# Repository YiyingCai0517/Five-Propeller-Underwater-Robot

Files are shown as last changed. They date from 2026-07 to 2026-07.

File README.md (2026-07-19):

# Five-Propeller Underwater Robot | 五推进器水下机器人

[中文](#中文说明) · [English](#english-version) · [中文独立版 / Chinese-only version](README.zh-CN.md)






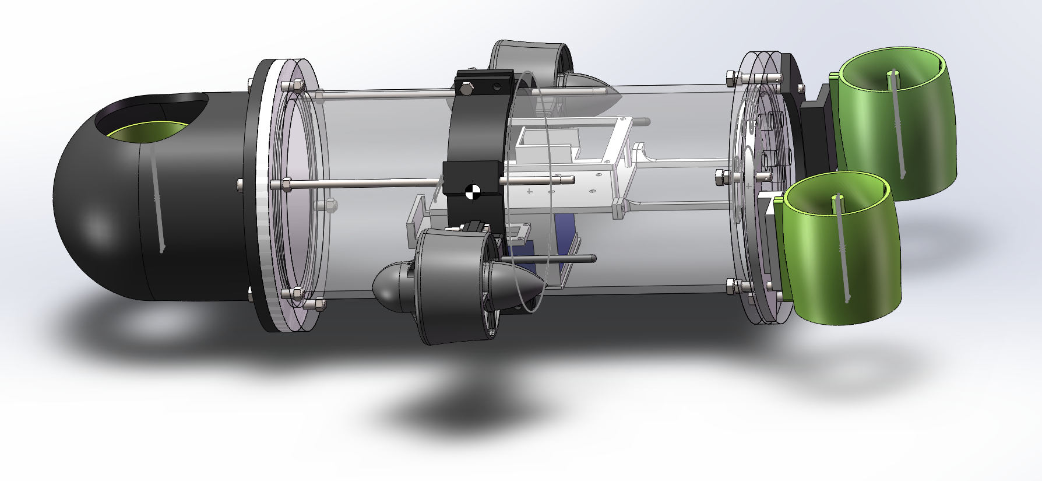
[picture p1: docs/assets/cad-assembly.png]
SolidWorks 最终装配体 / Final SolidWorks assembly


## 中文说明

本项目是一款基于 STM32F407 和 FreeRTOS 的小型五推进器水下机器人课程设计。机器人采用三个垂直推进器控制升沉、俯仰和横滚，两个水平推进器控制前进、后退和偏航。仓库已将嵌入式固件、SolidWorks 机械设计、LoRa 上位机、Python 六自由度仿真、ROS1 模型、样机照片和工程说明整理为可直接浏览和审查的源文件。

### 项目功能

- 五推进器驱动：三个垂直推进器控制升沉、俯仰和横滚，两个水平推进器控制纵向运动和偏航。
- 支持 `IDLE`、定深 `HOVER`、航向保持 `AUTO`、绝对航向转向 `TURN` 和定时方形轨迹 `SQUARE` 模式。
- 使用四个 PID 控制环、解析式推进器混控和按比例限幅。
- FreeRTOS 分离控制、压力采样、通信和心跳任务。
- 使用 H30 串口 IMU、MS5837-30BA 压力传感器、E22-400T30D LoRa 和五路 ESC PWM，并以 2 Hz 返回遥测数据。
- 提供基于 Python/pyserial 的指令终端、状态显示和 CSV 日志记录。
- 提供独立 Python 六自由度任务仿真和 ROS1 URDF/STL 可视化模型。

### 样机与水池试验

| 最终装配样机 | 方形轨迹试验画面 |
| --- | --- |
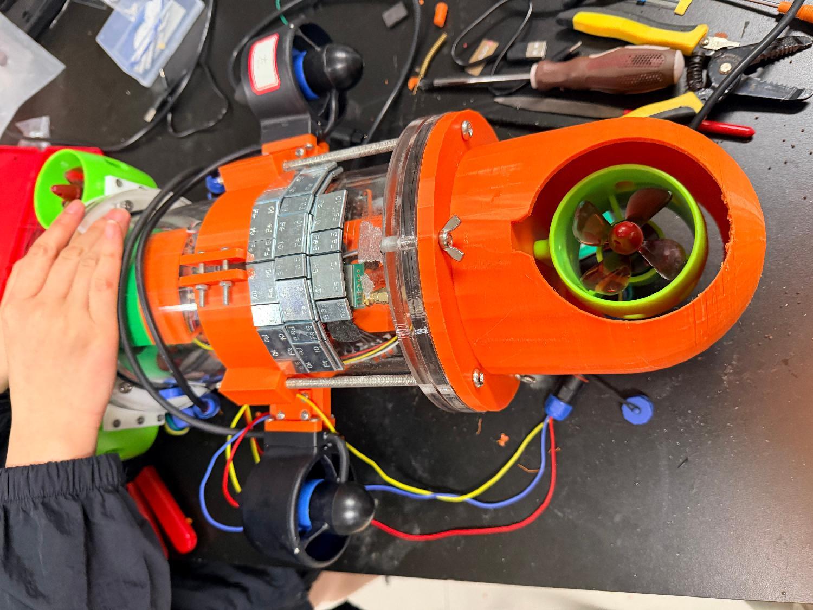
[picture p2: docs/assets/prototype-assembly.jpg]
最终装配阶段的样机
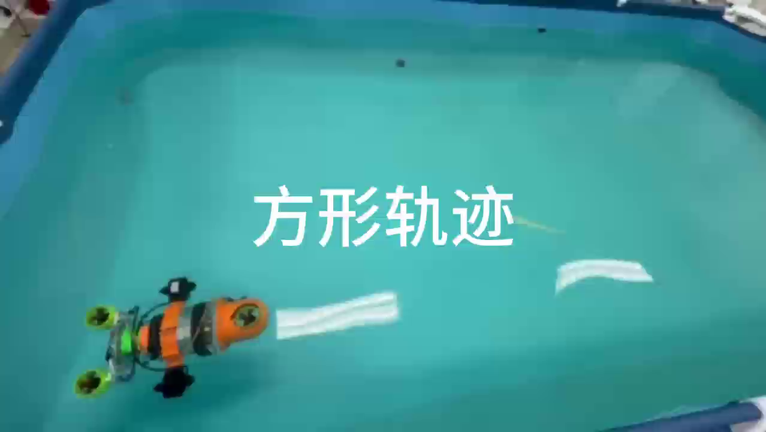
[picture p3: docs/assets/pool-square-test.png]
水池方形轨迹试验画面
|  |  |

### 系统组成

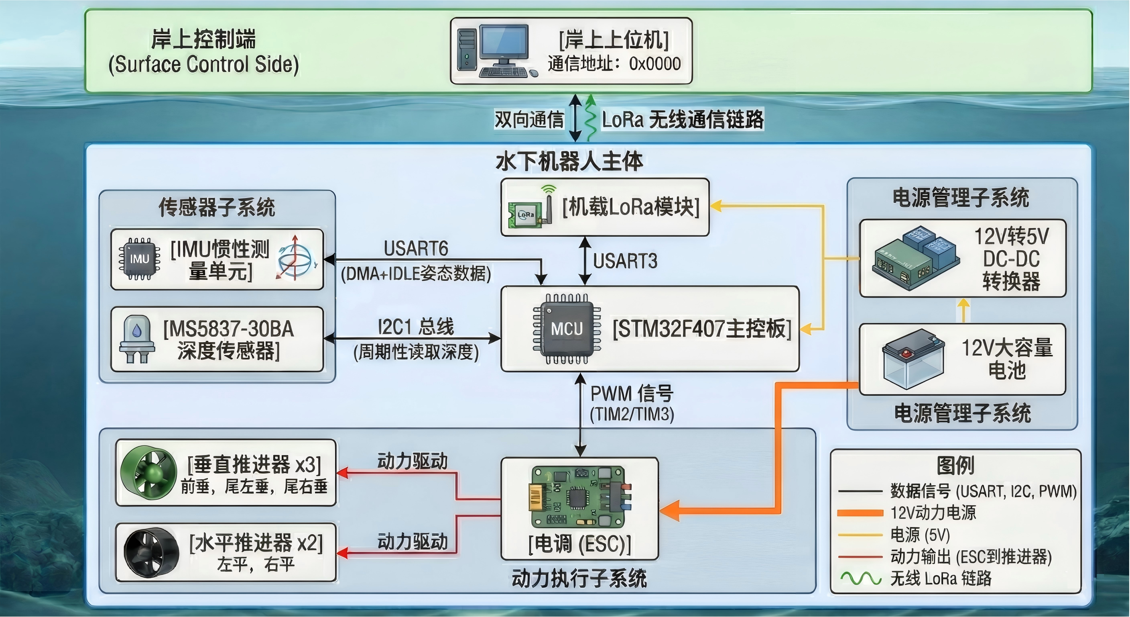
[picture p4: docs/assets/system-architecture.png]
电气与通信架构


| 层级 | 主要组件 | 职责 |
| --- | --- | --- |
| 传感器 | H30 IMU、MS5837-30BA | 姿态、加速度、压力和深度测量 |
| 控制器 | STM32F407 + FreeRTOS | 状态机、PID、推进器混控和通信 |
| 执行机构 | 5 个 ESC 驱动推进器 | 升沉、俯仰、横滚、纵向运动和偏航 |
| 通信 | E22 LoRa（UART/DMA） | 指令接收和遥测发送 |
| 上位机 | Python + pyserial | 指令输入、状态显示和 CSV 日志 |
| 数值仿真 | Python + NumPy/Matplotlib | 六自由度模型和可复现实例 |
| 机器人可视化 | ROS1 URDF/STL | 几何模型和关节显示 |

### 硬件概况

主要硬件包括 STM32F407、H30 IMU、MS5837-B30 压力传感器、E22-400T30D 无线模块、三星 21700-50S 电芯定制电池组、两个已安装的 Viocean T60 水平推进器、三个垂直推进器，以及直径 130 mm、长度 250 mm 的透明耐压舱。项目总预算为人民币 2,441.3 元。数量差异、备用推进器和缺失的电气资料请参见[硬件与预算说明](docs/hardware.md)。

### 仓库结构

```text
Five-Propeller-Underwater-Robot/
├── firmware/                 STM32F407 CubeMX/CMake 固件
├── tools/pc/                 Python LoRa 上位机与遥测记录工具
├── mechanical/solidworks/    SolidWorks 零件与装配体源文件
├── simulation/python/        独立六自由度数值仿真
├── simulation/ros/           ROS1 URDF/STL 可视化包
├── docs/                     架构、算法、协议、硬件和代码审查文档
├── .github/                  Issue 与 Pull Request 模板
├── README.md                 中英双语主页
├── README.zh-CN.md           独立中文说明
└── LICENSE
```

### 快速开始

#### 1. 查看或编译固件

需要 CMake 3.22+、Ninja 和 Arm GNU Toolchain（`arm-none-eabi-gcc`）。

```bash
cd firmware
cmake --preset Debug
cmake --build --preset Debug
```

可使用 STM32CubeMX 查看或重新生成 `firmware/unify_v1_0307.ioc`。烧录前必须结合实物核对引脚、接线、PWM 中值与范围、传感器设置、电机方向和安全限值。详见[固件说明](firmware/README.md)。

#### 2. 运行 LoRa 上位机

```bash
python -m venv .venv
# Windows PowerShell: .venv\Scripts\Activate.ps1
python -m pip install -r tools/pc/requirements.txt
python tools/pc/lora_pc.py COM6 9600
```

请将 `COM6` 和 `9600` 替换为实际串口和波特率。详见[上位机说明](tools/pc/README.md)和[通信协议](docs/protocol.md)。

#### 3. 运行数值仿真

```bash
cd simulation/python
python -m pip install -r requirements.txt
python scripts/smoke_test.py
python run_all_tasks.py
```

仿真参数目前属于工程假设，仿真误差（尤其是很小的深度 RMSE）不能作为实物精度。详见[仿真说明](simulation/python/README.md)。

#### 4. 查看 ROS 模型

将 `simulation/ros/simulatedrobot` 放入 ROS1 catkin 工作空间，然后运行：

```bash
roslaunch simulatedrobot display_fixed.launch
```

该包用于几何可视化，不是经过验证的水下 Gazebo 动力学模型。详见[ROS/URDF 说明](simulation/ros/README.md)。

### 固件控制模式

| 模式 | 行为 |
| --- | --- |
| `IDLE` | 输出中性 PWM，并清空所有 PID 状态 |
| `HOVER` | 保持目标深度和水平姿态，纵向推力为零 |
| `AUTO` | 保持目标深度和进入模式时的航向，同时施加设定纵向推力 |
| `TURN` | 停止纵向推进并转到指定偏航角；误差进入 ±3° 后切换为悬停 |
| `SQUARE` | 交替执行定时直线航段和 90° 转向，共完成四条边 |

任务时序、PID 参数、控制方程、混控映射、仿真差异和调参顺序见[控制算法说明](docs/control-algorithm.md)。

### 项目文档

- [系统架构与数据流](docs/architecture.md)
- [控制算法](docs/control-algorithm.md)
- [LoRa 通信协议](docs/protocol.md)
- [硬件与预算](docs/hardware.md)
- [静态代码审查结果](docs/code-review.md)
- [安全说明与已知限制](docs/safety.md)
- [机械设计文件](mechanical/README.md)

### 参与贡献与许可证

请阅读[贡献指南](CONTRIBUTING.md)。源代码、配置和文档应以普通 Git 文件提交，请勿重新提交编译目录、IDE 缓存、仿真输出、遥测日志或替代用 ZIP 压缩包。本仓库采用 [MIT License](LICENSE)；STM32 HAL、CMSIS、FreeRTOS 和其他第三方组件仍遵循各自源码目录中的许可声明。

---

## English version

This repository contains an STM32F407/FreeRTOS course project for a compact underwater robot with three vertical and two horizontal thrusters. It brings the firmware, SolidWorks design, PC LoRa tool, Python 6-DOF simulation, ROS1 model, prototype images, and engineering notes together as directly reviewable source files.

> [!CAUTION]
> This is a teaching and research prototype, not a certified underwater vehicle. The current depth conversion appears to be approximately 10× too small, and active modes do not yet have a LoRa command-loss watchdog. Read [Safety and known limitations](docs/safety.md), and verify wiring, motor direction, and protection measures before powering the thrusters or attempting closed-loop pool tests.

### Highlights

- Five-thruster actuation: three vertical units for heave, pitch, and roll, plus two horizontal units for surge and yaw.
- `IDLE`, depth `HOVER`, heading-hold `AUTO`, absolute-yaw `TURN`, and timed `SQUARE` modes.
- Four firmware PID loops with an analytic mixer and proportional saturation handling.
- FreeRTOS separation of control, pressure sampling, communication, and heartbeat work.
- H30 serial IMU, MS5837-30BA pressure sensor, E22-400T30D LoRa, five ESC PWM channels, and 2 Hz telemetry.
- Python/pyserial command console with live status and CSV logging.
- Standalone Python 6-DOF task simulation and ROS1 URDF/STL visualization.

### Prototype and pool test

The images in the [Chinese section](#样机与水池试验) show the final assembly and a square-path pool test. The course report records demonstrations of depth control, straight motion, turning, and a timed square sequence. These tests establish prototype feasibility; they do not establish a pressure rating, navigation accuracy, or safety certification.

### System overview

| Layer | Main components | Responsibility |
| --- | --- | --- |
| Sensors | H30 IMU, MS5837-30BA | Attitude, acceleration, pressure, and depth |
| Controller | STM32F407 + FreeRTOS | State machine, PID, mixing, and communication |
| Actuation | 5 ESC-driven thrusters | Heave, pitch, roll, surge, and yaw |
| Communication | E22 LoRa over UART/DMA | Commands and telemetry |
| Ground station | Python + pyserial | Command entry, display, and CSV logging |
| Numerical simulation | Python + NumPy/Matplotlib | 6-DOF model and repeatable task examples |
| Robot visualization | ROS1 URDF/STL | Geometry and joint display |

### Hardware snapshot

The report lists an STM32F407, H30 IMU, MS5837-B30 sensor, E22-400T30D radio, a custom Samsung 21700-50S battery pack, two installed Viocean T60 horizontal thrusters, three vertical thrusters, and a 130 mm × 250 mm transparent housing. Its historical project total is CNY 2,441.3. See [Hardware and budget](docs/hardware.md) for quantities, the spare-thruster discrepancy, and missing electrical documentation.

### Repository layout

The bilingual directory tree is shown in the [Chinese section](#仓库结构). The two original ZIP archives were replaced by source trees so GitHub can browse, search, diff, and review the project directly.

### Quick start

#### 1. Inspect or build the firmware

Requirements: CMake 3.22+, Ninja, and Arm GNU Toolchain (`arm-none-eabi-gcc`).

```bash
cd firmware
cmake --preset Debug
cmake --build --preset Debug
```

Use STM32CubeMX to inspect or regenerate `firmware/unify_v1_0307.ioc`. Pin assignments, wiring, PWM neutral/range, sensor configuration, motor direction, and safety limits must be verified against the actual hardware before flashing. See [Firmware notes](firmware/README.md).

#### 2. Run the PC LoRa console

```bash
python -m venv .venv
# Windows PowerShell: .venv\Scripts\Activate.ps1
python -m pip install -r tools/pc/requirements.txt
python tools/pc/lora_pc.py COM6 9600
```

Replace `COM6` and `9600` with the real port and configured baud rate. See [PC tool instructions](tools/pc/README.md) and the [protocol specification](docs/protocol.md).

#### 3. Run the numerical simulation

```bash
cd simulation/python
python -m pip install -r requirements.txt
python scripts/smoke_test.py
python run_all_tasks.py
```

Simulation parameters are provisional engineering assumptions. Numerical errors—especially very small depth RMSE values—must not be presented as measured vehicle accuracy. See [Simulation notes](simulation/python/README.md).

#### 4. View the ROS model

Place `simulation/ros/simulatedrobot` in a ROS1 catkin workspace and run:

```bash
roslaunch simulatedrobot display_fixed.launch
```

The package is a geometry visualization export, not a validated underwater Gazebo model. See [ROS/URDF notes](simulation/ros/README.md).

### Firmware control modes

| Mode | Behavior |
| --- | --- |
| `IDLE` | Output neutral PWM and reset all PID state |
| `HOVER` | Hold target depth, level pitch/roll, and use zero surge |
| `AUTO` | Hold depth and the entry heading while applying requested surge |
| `TURN` | Stop surge and rotate to a requested yaw; switch to hover within ±3° |
| `SQUARE` | Alternate timed straight legs and 90° yaw turns for four sides |

See [Control algorithm](docs/control-algorithm.md) for task timing, gains, equations, mixer mapping, simulation differences, and tuning order.

### Documentation

- [Architecture and data flow](docs/architecture.md)
- [Control algorithm](docs/control-algorithm.md)
- [LoRa protocol](docs/protocol.md)
- [Hardware and budget](docs/hardware.md)
- [Static code review findings](docs/code-review.md)
- [Safety and known limitations](docs/safety.md)
- [Mechanical design files](mechanical/README.md)

### Current engineering limitations

- The pressure-to-depth conversion must be corrected and physically calibrated.
- Command and IMU parsers need stricter bounds, exact-length, and finite-value validation.
- Active modes need an independent command-age watchdog.
- PID gains and simulator hydrodynamic parameters are not backed by a committed identification dataset.
- Hardware schematics, connector pinouts, fusing, BMS details, and a verified current budget are missing.
- The URDF remains a simplified visualization model without underwater dynamics plugins.

Details and suggested corrections are tracked in [Code review findings](docs/code-review.md).

### Contributing and license

See [CONTRIBUTING.md](CONTRIBUTING.md). Keep source, configuration, and documentation as normal Git files; do not recommit build directories, IDE caches, simulation outputs, telemetry logs, or replacement ZIP archives. This repository is released under the [MIT License](LICENSE). STM32 HAL, CMSIS, FreeRTOS, and other third-party components retain the notices included in their own source directories.

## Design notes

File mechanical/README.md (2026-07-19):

# Mechanical design files

`solidworks/` contains the native SolidWorks parts and assemblies recovered from the original archive/local project directory.

CAD assembly

## Suggested entry points

- `solidworks/装配体（水平推进器简化）.SLDASM` — simplified horizontal-thruster assembly;
- `solidworks/外径130x300密封舱总装2.SLDASM` — pressure-housing assembly;
- `solidworks/分隔板+连接件.SLDASM` — internal divider assembly;
- `solidworks/头部圆壳.SLDPRT` — nose structure;
- `solidworks/尾部垂推连接件1.SLDPRT` and `尾部垂推连接件2.SLDPRT` — rear vertical-thruster mounts.

File names preserve the original Chinese names so SolidWorks assembly references are less likely to break.

## Reported prototype data

| Property | Reported value |
| --- | ---: |
| External assembly mass | approximately 3.451 kg |
| Displaced volume | approximately 2.387 × 10⁶ mm³ |
| Estimated buoyancy | approximately 50.8 N |
| Centre-of-mass Z | 223.254 mm in the report's CAD frame |
| Centre-of-buoyancy Z | 230.746 mm in the report's CAD frame |
| Vertical separation | approximately 7.49 mm, buoyancy centre above mass centre |

These are report snapshots, not independently recalculated values. The directory includes names referring to both 250 mm and 300 mm housings; confirm the active assembly, units, configurations, missing references, and final manufactured dimensions before producing parts.

## Recommended workflow

1. Open the top assembly in the same or a newer SolidWorks version.
2. Resolve all references without renaming source files.
3. Confirm document units and material assignments.
4. Recalculate mass properties with the exact battery, electronics, fasteners, seals, and wiring.
5. Export neutral formats and drawings for fabrication in a reviewed release rather than treating native CAD alone as manufacturing documentation.

The files do not establish a certified pressure rating. See `docs/safety.md` before leak or immersion testing.

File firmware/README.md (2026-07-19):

# STM32F407 firmware

This directory is the source form of the original STM32CubeMX project. It targets an STM32F407 and uses STM32 HAL, CMSIS-RTOS v2, and FreeRTOS.

## Important files

| Path | Purpose |
| --- | --- |
| `unify_v1_0307.ioc` | STM32CubeMX configuration |
| `Core/Src/app_robot.c` | Control, depth, command, and telemetry tasks |
| `Core/Src/pid.c` | PID implementation |
| `Core/Src/mixer.c` | Five-thruster mixer |
| `Core/Src/motor_pwm.c` | TIM2/TIM3 PWM output |
| `Core/Src/MS5837.c` | Pressure sensor driver |
| `Core/Src/analysis_data.c` | H30 IMU protocol parser |
| `Core/Src/freertos.c` | Task, queue, semaphore, and mutex creation |

## Peripheral map from source

| Interface | Use |
| --- | --- |
| USART3 + DMA/IDLE | E22 LoRa commands and telemetry |
| USART6 + DMA/IDLE | H30 IMU stream |
| I²C1 | MS5837 depth sensor |
| TIM2 CH2/3/4 | Three vertical ESC PWM channels |
| TIM3 CH3/4 | Two horizontal ESC PWM channels |

Always verify this table against the `.ioc`, generated pin definitions, PCB, and actual wiring. Some source comments and pin assignments may not describe the final board revision consistently.

## Build

Install CMake 3.22+, Ninja, and the Arm GNU Toolchain, then make sure `arm-none-eabi-gcc` is available in `PATH`.

```bash
cmake --preset Debug
cmake --build --preset Debug
```

Release build:

```bash
cmake --preset Release
cmake --build --preset Release
```

The generated ELF is placed under `build/<preset>/`. Flashing is not scripted in this repository; use the debugger/programmer that matches your hardware and verify the exact target before writing flash.

## Configuration before use

Review at minimum:

- LoRa destination addresses and channel in `Core/Src/app_robot.c` and `tools/pc/lora_pc.py`;
- IMU output protocol/rate and USART6 baud settings;
- PWM frequency, neutral, minimum, maximum, motor order, and direction;
- depth conversion, water density, atmospheric baseline, and test depth limit;
- PID gains and mixer coefficients;
- command/IMU watchdog behavior.

Do not run physical closed-loop tests until the high-priority findings in `docs/code-review.md` and the checklist in `docs/safety.md` have been addressed.

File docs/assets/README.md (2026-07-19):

# Image provenance

The images in this directory were extracted from the project owner's course report and renamed for repository use.

| File | Report figure / purpose |
| --- | --- |
| `cad-assembly.png` | Final SolidWorks assembly |
| `thruster-layout.png` | Top view of thruster placement and internal divider position |
| `electronics-layout.png` | Internal divider and electronics layout |
| `prototype-assembly.jpg` | Final prototype assembly state |
| `system-architecture.png` | Electrical and communication architecture |
| `pool-straight-turn-test.png` | Pool straight/turn test frame |
| `pool-square-test.png` | Pool square-path test frame |

The report itself is not committed because its technical content is summarized in the repository documentation and it is substantially larger than the extracted web images.

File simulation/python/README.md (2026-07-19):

# Python 6-DOF simulation

This module provides a standalone numerical model for algorithm study and repeatable demonstrations. It includes five thrust vectors, simplified 6-DOF dynamics, linear/quadratic damping, restoring terms, actuator lag, task controllers, and constrained weighted least-squares allocation.

## Install and test

From this directory:

```bash
python -m venv .venv
# Windows PowerShell: .venv\Scripts\Activate.ps1
python -m pip install -r requirements.txt
python scripts/smoke_test.py
```

## Run all examples

```bash
python run_all_tasks.py
```

Skip plots for a faster headless run:

```bash
python run_all_tasks.py --no-plots --output outputs/latest
```

Run a single task:

```bash
python scripts/run_task.py depth_forward
python scripts/run_task.py turn_90deg
python scripts/run_task.py rectangle_track
```

Generated CSV, JSON, and PNG files are written under `outputs/` and ignored by Git.

## Source map

| File | Purpose |
| --- | --- |
| `src/underwater_5thruster_sim/dynamics.py` | Rigid-body integration, damping, restoring force, actuator lag |
| `controllers.py` | Depth, surge, roll, pitch, and yaw control laws |
| `allocation.py` | Weighted least-squares actuator allocation with clipping |
| `robot_params.py` | Coordinate transform, mass assumptions, damping, thruster geometry |
| `tasks.py` | Forward, turn, and rectangular waypoint tasks |
| `plotting.py` | Result figures |

## Model limitations

- Mass, inertia, added mass, damping, restoring stiffness, and actuator time constant are provisional values derived from CAD interpretation and engineering assumptions.
- Thruster output is a symmetric command-to-force model, not a measured PWM/RPM/thrust curve.
- The model omits free-surface effects, tether forces, radio behavior, waves, turbulence, leakage, battery voltage sag, detailed sensor noise, and controller timing jitter.
- Very small simulated depth RMSE values demonstrate consistency of the assumed model and controller; they are not physical accuracy claims.
- The simulator control law and allocator are related to, but not identical to, the STM32 PID and analytic mixer.

Calibrate the model with tank data before using it to select real-world gains or safety limits.

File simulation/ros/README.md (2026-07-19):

# ROS1 URDF visualization

`simulatedrobot/` is a SolidWorks-exported ROS1 package containing URDF, STL meshes, and launch files.

## Recommended visualization

Copy or symlink `simulatedrobot` into a catkin workspace `src/` directory, build the workspace, source it, and launch the corrected visualization variant:

```bash
catkin_make
source devel/setup.bash
roslaunch simulatedrobot display_fixed.launch
```

For Gazebo geometry spawning:

```bash
roslaunch simulatedrobot gazebo_fixed.launch
```

The `*_fixed` files use `simulatedrobot_fixed.urdf`, which corrects the obviously invalid zero inertia of `rfw` and the likely base inertial coordinate swap while preserving the original export for comparison.

## Known limitations

- The package targets ROS1 and has not been migrated to ROS2.
- The original `display.launch` references a missing `urdf.rviz` configuration.
- Detailed visual meshes are also used for collision geometry.
- Inertial values require physical/CAD verification.
- There are no buoyancy, hydrodynamic drag, added-mass, current, thruster, battery, communication, IMU, or depth-sensor plugins.
- Spawning the model in Gazebo is not equivalent to an underwater dynamics simulation.

Use `simulation/python/` for the standalone numerical task examples, with the limitations documented there.

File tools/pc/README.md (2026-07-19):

# PC LoRa ground station

`lora_pc.py` is an interactive serial console for command transmission, telemetry display, and optional CSV logging.

## Install

Python 3.10 or later is recommended.

```powershell
python -m venv .venv
.\.venv\Scripts\Activate.ps1
python -m pip install -r tools\pc\requirements.txt
```

On macOS/Linux, activate with `source .venv/bin/activate`.

## Find the serial port

Windows PowerShell:

```powershell
Get-CimInstance Win32_SerialPort | Select-Object DeviceID, Description
```

Linux:

```bash
ls /dev/ttyUSB* /dev/ttyACM*
```

## Run

From the repository root:

```powershell
python tools\pc\lora_pc.py COM6 9600
```

Replace `COM6` and `9600` with the actual device and configured baud rate.

## Commands

| Command | Example | Meaning |
| --- | --- | --- |
| `hover <depth>` | `hover 0.15` | Hold 0.15 m depth |
| `move <surge>` | `move 0.2` | Apply normalized forward thrust |
| `stop` | `stop` | Return to idle/neutral |
| `turn <yaw>` | `turn 90` | Turn to an absolute yaw in degrees |
| `square <seconds> <surge>` | `square 5 0.2` | Timed four-leg demonstration |
| `log start` / `log stop` | `log start` | Write telemetry CSV in the current directory |
| `help` | `help` | Show help |
| `quit` | `quit` | Close the serial port |

The E22 fixed-transmission address and channel are constants near the top of the script. They must match the radio configuration and firmware. See `docs/protocol.md`.

## Safety

The console currently validates only some surge limits. The firmware does not yet have a command-loss watchdog. Keep an independent physical power disconnect available, send `stop` before closing the tool, and do not rely on the radio link as the only emergency stop.

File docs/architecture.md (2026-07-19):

# System architecture

This page describes the repository as it exists in source code. It separates the embedded controller, the PC ground station, and the two simulation paths so that readers do not have to infer the design from archived projects.

```mermaid
flowchart LR
    PC["Python ground station"] <-->|"LoRa / UART3\ncommands + 2 Hz telemetry"| MCU["STM32F407 + FreeRTOS"]
    IMU["H30 IMU\nUART6 + DMA/IDLE"] --> MCU
    DEPTH["MS5837-30BA\nI²C1 / 20 Hz"] --> MCU
    MCU -->|"TIM2/TIM3 PWM"| ESC["5 ESC channels"]
    ESC --> V["3 vertical thrusters"]
    ESC --> H["2 horizontal thrusters"]
    SIM["Python 6-DOF simulation"] -. "algorithm study" .-> MCU
    ROS["ROS1 URDF/STL"] -. "geometry visualization" .-> SIM
```

Detailed electrical architecture

## Embedded task model

| Task | Priority / trigger | Main responsibility |
| --- | --- | --- |
| `Task_Control` | Realtime; released by an IMU frame | Parse attitude, update speed estimate, process commands, run four PID loops, mix and write PWM |
| `Task_Depth` | Normal; nominal 50 ms loop | Read the MS5837 and update depth |
| `Task_Comms` | Below normal; receive event plus 500 ms timeout | Parse LoRa commands and send telemetry |
| `defaultTask` | Low; 500 ms loop | Heartbeat LED |

Shared robot state is protected by `Mutex_State`. Commands cross from the communication task to the control task through `Queues_Cmd`. UART IDLE interrupts release the IMU and LoRa semaphores.

## Repository-to-runtime map

| Repository path | Runtime role |
| --- | --- |
| `firmware/Core/Src/app_robot.c` | Mode state machine and real-time control loop |
| `firmware/Core/Src/pid.c` | Position-form PID and yaw-angle normalization |
| `firmware/Core/Src/mixer.c` | Five-thruster analytic mixer and normalization |
| `firmware/Core/Src/MS5837.c` | Pressure conversion and depth calculation |
| `firmware/Core/Src/analysis_data.c` | IMU binary protocol parser |
| `tools/pc/lora_pc.py` | Command console, telemetry parser, CSV logger |
| `simulation/python/` | Standalone 6-DOF numerical model and task controllers |
| `simulation/ros/simulatedrobot/` | ROS1 geometry, joints, RViz/Gazebo launch files |

## Coordinate and sign conventions

- Firmware control values use depth in metres and attitude in degrees.
- Normalized thruster commands are intended to be in `[-1, 1]`.
- The Python simulator uses body X forward, body Y left, body Z up; world depth is `-world_z`.
- The original SolidWorks-exported URDF uses its CAD export frame. Do not assume it matches the simulator body frame without applying the transform documented in `simulation/python/src/underwater_5thruster_sim/robot_params.py`.

## What is and is not validated

The physical prototype demonstrated basic motion and communication in a pool. The Python model is useful for repeatable algorithm experiments, but its hydrodynamic coefficients and thruster model are provisional. The ROS package is primarily a visualization export and does not include validated buoyancy, drag, added-mass, thruster, or sensor plugins.

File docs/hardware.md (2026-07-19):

# Hardware and budget snapshot

This page is transcribed from the course report's project budget. It documents the prototype configuration; it is not a current purchasing recommendation, price quote, or complete wiring bill of materials.

Prototype during final assembly

## Installed system

| Subsystem | Selected hardware | Role |
| --- | --- | --- |
| Main controller | STM32F407 board | FreeRTOS tasks, control, communication, PWM |
| Attitude sensor | H30 IMU | Yaw, pitch, roll, and acceleration over UART6 |
| Depth sensor | MS5837-B30 / MS5837-30BA | Pressure and depth feedback over I²C1 |
| Radio | E22-400T30D LoRa | Commands and telemetry over UART3 |
| Horizontal propulsion | 2 × Viocean T60 installed | Surge and differential yaw |
| Vertical propulsion | 3 × vertical thruster | Heave, pitch, and roll |
| Battery | Custom pack using Samsung 21700-50S cells | Reported 5000 mAh / approximately 111 Wh |
| DC-DC | 5 V / 3 A module | Low-voltage electronics supply |
| Pressure housing | 130 mm × 250 mm transparent cylinder | Dry electronics enclosure |
| Main switch | M22 waterproof switch | External power isolation |

The report describes three horizontal T60 units in the purchase list while the mechanical and control design installs two. The third purchased unit is therefore treated here as a spare; verify the actual inventory before ordering or assembling.

## Historical budget

| Item | Model / specification | Unit price (CNY) | Quantity | Subtotal (CNY) |
| --- | --- | ---: | ---: | ---: |
| Pressure housing | 130 mm × 250 mm | 370.0 | 1 | 370.0 |
| Horizontal thruster | Viocean T60 | 255.0 | 3 | 765.0 |
| Vertical thruster | Not recorded | 55.0 | 3 | 165.0 |
| Vent / cable gland bolt | M10 | 20.0 | 9 | 180.0 |
| Main controller | STM32F407 | 87.0 | 1 | 87.0 |
| LoRa module | E22-400T30D | 38.8 | 1 | 38.8 |
| DC-DC converter | 5 V / 3 A | 22.7 | 1 | 22.7 |
| Battery | Samsung 21700-50S pack | 209.5 | 1 | 209.5 |
| Attitude sensor | H30 | 254.0 | 1 | 254.0 |
| Wireless debugger | Not recorded | 95.8 | 1 | 95.8 |
| Depth sensor | MS5837-B30 | 209.0 | 1 | 209.0 |
| Waterproof switch | M22 | 24.9 | 1 | 24.9 |
| Self-tapping screws | M2.3 × 18 | — | 100 | 3.3 |
| Bolts and nuts | M3 × 20 / M5 × 30 | — | 130 | 16.3 |
| **Total** |  |  |  | **2441.3** |

Prices are historical values copied from the report and may omit shipping, fabrication, consumables, chargers, test equipment, replacement parts, and safety equipment.

## Electrical information still needed

The repository does not yet contain a reviewed schematic, connector pinout, fuse selection, maximum-current calculation, battery protection specification, or waterproof connector wiring table. Add those before treating this as a reproducible hardware build.

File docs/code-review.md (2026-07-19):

# Code review findings

This is a static review of the checked-in firmware, PC tool, and ROS export. It records risks without silently changing the behavior of a tested prototype. Severity reflects potential impact during physical operation.

## High priority

| Area | Finding | Impact | Recommended correction |
| --- | --- | --- | --- |
| Depth conversion | `MS5837_30BA_data.Pressure` is already stored in mbar after the final `/ 10`, but `MS5837_GetDepth()` applies the coefficient for 0.1 mbar. The reported depth is therefore approximately 10× too small. | Incorrect setpoint tracking and unsafe depth control | Use approximately `delta_mbar * 0.0101972f` for fresh water, then calibrate density and atmospheric zero with a known depth |
| Command parser | Function payload lengths are not required to be exact, and float fields are not checked with `isfinite()` or physical bounds. | Malformed, `NaN`, or extreme commands can propagate into state, angle normalization, timing, and PWM logic | Require exact lengths and validate depth, surge, yaw, and edge time before queueing |
| Link safety | There is no command-age or LoRa-loss watchdog in active modes. | The last motion command can continue after the operator link is lost | Timestamp each valid command and force neutral/idle after a short, tested timeout |
| IMU parser | TLV parsing reads `payload->data_len` before proving that two TLV header bytes remain; malformed lengths can underflow `payload_len` and advance outside the frame. | Out-of-bounds reads or stale/invalid attitude data | Check remaining bytes before every header and payload access; reject the entire frame on inconsistency |

## Medium priority

| Area | Finding | Impact / next step |
| --- | --- | --- |
| DMA length | `imu_data_len` is `uint8_t` although the buffer is 256 bytes. A full DMA buffer produces `256`, which wraps to zero. | Change the variable and related calculations to `uint16_t` or `size_t` |
| Semaphore initialization | Both binary semaphores are created with an initial count of 1. | Control and communication tasks can run once before real data arrives; initialize them to 0 |
| MS5837 errors | I²C return codes and repeated CRC failure are not propagated. Transactions use 10 s timeouts. | A failed sensor can block the depth task or leave stale values; use bounded timeouts, return status, and declare sensor data invalid |
| MS5837 OSR names | Constants labelled `OSR_8192` use commands `0x44` and `0x54`, which correspond to a lower oversampling setting in the sensor command map. | Rename or correct the commands and use the matching conversion delay |
| PID transitions | Most mode changes do not reset selected integrators or derivative history. | Carry-over can cause a transient when a new target or mode is selected; use explicit bumpless transfer/reset rules |
| PID robustness | Derivative is taken directly from error without filtering, and integration continues while output is saturated. | Noise amplification and windup; add derivative filtering and conditional/back-calculation anti-windup |
| Mixer saturation | All five thrusters are normalized as one group. | Horizontal saturation can reduce vertical authority and vice versa; use group-aware limits or constrained allocation |
| Speed estimate | Accelerometer integration with fixed per-sample decay depends on update rate and accumulates bias. | Treat as indicative telemetry; use time-constant-based decay and a suitable velocity sensor/fusion method for navigation |
| Protocol evolution | No version, sequence number, acknowledgement, or duplicate detection. | Hard to diagnose packet loss and maintain compatibility; add these fields in a versioned frame |

## ROS / URDF findings

- The original `base_link` inertial origin places one coordinate about 1.27 m away from a body whose local mesh extent is much smaller, indicating a likely coordinate swap in the SolidWorks export.
- The original `rfw` link has zero mass and zero inertia, which is invalid for physics simulation.
- Visual meshes are also used as collision meshes and are unnecessarily detailed for real-time collision checking.
- `display.launch` references a missing `urdf.rviz` file.
- The package has no underwater dynamics, buoyancy, drag, thruster, current, or sensor plugins.

`simulatedrobot_fixed.urdf` and the `*_fixed.launch` files preserve the exported package while correcting the two inertial defects for visualization. They still do not make the package a validated underwater physics model.

## Validation limits

The review environment did not have the target robot, calibrated sensors, ESCs, or a water tank. Firmware behavior must be confirmed on a bench with propellers removed before any water test. See [Safety and known limitations](safety.md).

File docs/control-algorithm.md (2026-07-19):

# Control algorithm

The project contains two related control implementations:

- the STM32 firmware uses four position-form PID loops and an analytic five-thruster mixer;
- the Python simulator uses model-level PD/P control, feed-forward terms, and constrained weighted least-squares allocation.

They solve the same motion tasks but are not numerically identical. Simulation gains must not be copied directly to the physical robot.

## Firmware control loop

`Task_Control` waits for a valid IMU frame. For each control update it:

1. computes the elapsed time `dt`;
2. consumes at most one queued command and updates the mode state;
3. parses attitude and updates the short-term forward-speed estimate;
4. reads the current depth and targets under the state mutex;
5. advances the square-path or turn state machine;
6. computes depth, pitch, roll, and yaw PID outputs;
7. mixes them into five normalized commands and writes PWM.

If an IMU frame does not arrive within 200 ms, all PWM channels return to neutral and all PID states are reset.

## PID implementation

For each channel:

```text
e(k) = target - measurement
I(k) = clamp(I(k-1) + e(k) dt, -Imax, Imax)
D(k) = (e(k) - e(k-1)) / dt
u(k) = clamp(Kp e(k) + Ki I(k) + Kd D(k), umin, umax)
```

A symmetric error deadband is applied before integration and differentiation. Yaw error is normalized to `[-180°, 180°]` before entering the yaw PID.

### Firmware gains

| Channel | `Kp` | `Ki` | `Kd` | Output | Integral limit | Deadband |
| --- | ---: | ---: | ---: | ---: | ---: | ---: |
| Depth | 2.0 | 0.30 | 0.50 | ±1.0 | ±0.5 | 0.01 m |
| Pitch | 1.5 | 0.10 | 0.30 | ±0.5 | ±0.3 | 0.5° |
| Roll | 1.5 | 0.10 | 0.30 | ±0.5 | ±0.3 | 0.5° |
| Yaw | 1.0 | 0.05 | 0.20 | ±0.8 | ±0.3 | 1.0° |

These are initial prototype values. There is no committed system-identification data or water-test step-response dataset that validates them across operating conditions.

## Five-thruster mixer

Let `heave`, `pitch`, `roll`, `surge`, and `yaw` be normalized control requests. With all mixer coefficients currently set to `0.5`:

```text
front_vertical     = heave + 0.5 pitch
rear_left_vertical = heave - 0.5 pitch + 0.5 roll
rear_right_vertical= heave - 0.5 pitch - 0.5 roll
left_horizontal    = surge + 0.5 yaw
right_horizontal   = surge - 0.5 yaw
```

If any absolute output exceeds 1, every output is divided by the largest magnitude. This preserves the command direction in five-dimensional actuator space, but it also couples saturation between the vertical and horizontal groups. A future implementation may normalize those groups separately or use a constrained allocator with explicit priorities.

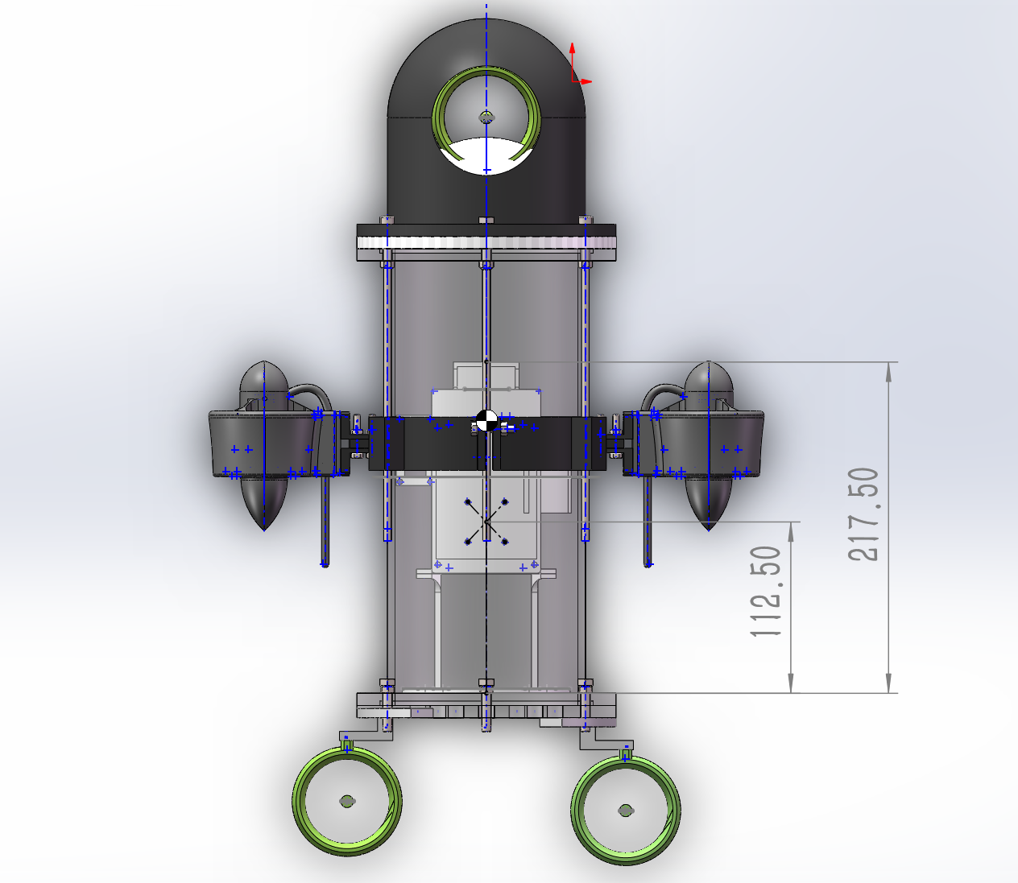
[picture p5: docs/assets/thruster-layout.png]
Thruster placement from the CAD model


## Modes and transitions

| Mode | Control behavior | Exit condition |
| --- | --- | --- |
| `IDLE` | Neutral PWM; reset all PID states | New command |
| `HOVER` | Hold depth and level attitude; zero surge | New command |
| `AUTO` | Hold depth and entry yaw; apply requested surge | New command |
| `TURN` | Zero surge; turn to requested yaw | Within ±3°, then switch to `HOVER` |
| `SQUARE` | Alternate timed straight legs and 90° turns | Four legs complete, then `IDLE` |

The square routine is time based. It does not measure horizontal position, so it is a demonstration sequence rather than geometric path tracking.

## Speed estimate

The firmware estimates forward speed by pitch-compensating IMU X acceleration, applying a ±0.1 m/s² deadband, integrating, decaying the result by 2% per update, and limiting it to ±3 m/s. This value is useful for short-term telemetry only; it is not a drift-free navigation measurement.

## Python simulation controller

The simulator models 6-DOF motion, linear and quadratic damping, restoring forces, actuator lag, five thrust vectors, and a weighted least-squares allocator. It provides three examples:

- depth-controlled forward motion;
- depth-controlled 90° turn;
- waypoint-guided rectangular tracking.

The simulator's very small depth errors are numerical results under assumed parameters, not measured prototype accuracy. See `simulation/python/README.md` for reproducible commands and model limitations.

## Recommended tuning order

1. Correct and calibrate the pressure-to-depth conversion.
2. Verify motor numbering, sign, neutral PWM, and emergency stop with propellers unloaded.
3. Tune pitch and roll at low output.
4. Tune depth while tethered and with a hard depth limit.
5. Tune yaw, then add low surge.
6. Validate command-loss behavior before running timed autonomous sequences.

Review [Safety and known limitations](safety.md) and [Code review findings](code-review.md) before physical testing.

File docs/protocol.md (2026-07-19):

# LoRa command and telemetry protocol

The application protocol uses little-endian IEEE-754 single-precision floats.

## Application frame

```text
AA 55 | function | payload_length | payload... | checksum
```

The checksum is the low eight bits of the sum of every byte from `AA` through the final payload byte.

When the E22 module is configured for fixed-point transmission, the PC prepends a three-byte destination header:

```text
address_high | address_low | channel | application_frame
```

The checked-in PC tool sends to STM32 address `0x0001` on channel `0x17`. Firmware telemetry targets PC address `0x0000` on the same channel. These values must match the actual E22 configuration.

## PC-to-robot commands

| Function | Name | Payload | Intended constraints |
| ---: | --- | --- | --- |
| `0x01` | `HOVER` | `float depth_m` | Non-negative and within the tested tank limit |
| `0x02` | `MOVE` | `float surge` | `[-1, 1]` |
| `0x03` | `STOP` | none | Immediate transition to idle |
| `0x04` | `TURN` | `float target_yaw_deg` | Finite angle; normalize before use |
| `0x05` | `SQUARE` | `float edge_time_s`, `float surge` | Positive bounded time; surge in `[-1, 1]` |

Example `STOP` application frame:

```text
AA 55 03 00 02
```

## Robot-to-PC telemetry

Telemetry function `0x80` carries a packed 33-byte payload:

| Offset | Type | Field | Unit |
| ---: | --- | --- | --- |
| 0 | `uint8` | mode | enum |
| 1 | `float` | current depth | m |
| 5 | `float` | yaw | deg |
| 9 | `float` | pitch | deg |
| 13 | `float` | roll | deg |
| 17 | `float` | target depth | m |
| 21 | `float` | target yaw | deg |
| 25 | `float` | estimated forward speed | m/s |
| 29 | `float` | requested surge | normalized |

Nominal telemetry interval is 500 ms.

## Parser limitations in the current firmware

The current protocol has no version, sequence number, acknowledgement, replay protection, or link watchdog. Firmware accepts payloads that are longer than required and does not reject non-finite floats or out-of-range depth/time/yaw values. The receive-length expression also uses an eight-bit result, which is unsafe for the 256-byte IMU DMA buffer.

Before extending the protocol:

- require the exact payload length for each function;
- validate `isfinite()` and physical bounds before queueing a command;
- use a 16-bit receive length for 256-byte buffers;
- add a monotonically increasing sequence number and explicit protocol version;
- add an independent command-age watchdog that returns the vehicle to neutral;
- document byte order and compatibility changes in this file.

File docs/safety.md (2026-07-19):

# Safety and known limitations

This is a course prototype, not a certified vehicle. Five exposed propellers, a high-energy battery, water, pressure seals, and remote commands create mechanical, electrical, and operational hazards.

## Do not use closed-loop depth control yet

The current pressure-to-depth coefficient appears approximately 10× too small. Correct it and validate the complete sensor path at several known depths before enabling `HOVER`, `AUTO`, `TURN`, or `SQUARE` in water.

The firmware also lacks a command-loss watchdog. An active mode can continue using its last target after the LoRa link disappears. Test and enable a neutral fail-safe before untethered operation.

## Bench checklist

- Remove propellers or mechanically isolate every thruster before firmware and direction tests.
- Use a current-limited supply for first power-up.
- Confirm 1500 µs neutral and each ESC's actual accepted range.
- Confirm motor indices, physical positions, positive directions, and yaw/pitch/roll signs one channel at a time.
- Verify the physical emergency power disconnect is accessible to a second person.
- Reject non-finite and out-of-range commands before motor output.
- Verify IMU timeout, command timeout, sensor-error handling, and reboot behavior.
- Keep strong motor power wiring separated from sensor and communication wiring.

## Pressure housing checklist

- Inspect O-rings, grooves, cable glands, threaded holes, windows, and printed parts before every test.
- Perform a dry vacuum-hold or equivalent leak test before adding electronics.
- Perform initial immersion with a dummy load or water indicator, not the live battery and controller.
- Increase depth and duration gradually; record leakage and deformation.
- Do not claim a depth rating until the complete assembled housing has been pressure tested with a documented safety factor.

## Water-test checklist

- Use a tether or physical recovery line even if control is wireless.
- Keep people clear of every propeller and never hold the vehicle while propulsion is enabled.
- Begin with low output and a hard software depth/output limit.
- Have one operator control the vehicle and another control the physical power disconnect.
- Stop immediately on leakage, unexpected motion, radio loss, sensor invalidity, battery heating, or unusual current.
- Treat LoRa underwater performance as range-limited; complete submersion can severely attenuate radio signals.

## Battery

The report describes a custom Samsung 21700-50S-based pack of approximately 111 Wh. The repository does not document the cell configuration, BMS, fusing, waterproofing, charger, current rating, or fault protection. Those details must be reviewed independently by a qualified person before reproduction.

## Software status

Known software and model issues are tracked in [Code review findings](code-review.md). Numerical simulation is not proof of physical stability, waterproofing, pressure tolerance, radio range, or safe autonomous behavior.

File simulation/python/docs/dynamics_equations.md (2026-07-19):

# 动力学模型

本工程使用一个适合课程仿真的 6 自由度水下机器人模型：

\[
M \dot{\nu} = \tau_{thruster} + \tau_{damping} + \tau_{restoring}
\]

\[
\dot{\eta} = J(\eta)\nu
\]

其中：

- \(\eta=[x,y,z,\phi,\theta,\psi]^T\)：世界坐标位置和 ZYX 欧拉角；
- \(\nu=[u,v,w,p,q,r]^T\)：体系速度；
- \(M\)：刚体质量/转动惯量加上附加质量的对角近似；
- \(\tau_{thruster}\)：五个推进器产生的合力和力矩；
- \(\tau_{damping}\)：线性阻尼和二次阻尼；
- \(\tau_{restoring}\)：重力、浮力、横滚/俯仰回复力矩。

## 推进器分配

第 \(i\) 个推进器位置为 \(r_i\)，单位推力方向为 \(d_i\)，最大推力为 \(T_{max,i}\)，归一化指令为 \(c_i\in[-1,1]\)：

\[
F_i = c_i T_{max,i} d_i
\]

\[
\tau_i = \begin{bmatrix}F_i \\ r_i \times F_i\end{bmatrix}
\]

合力矩为：

\[
\tau_{thruster}=A c
\]

控制器先给出期望广义力：

\[
\tau_d=[F_x,0,F_z,M_x,M_y,M_z]^T
\]

然后用加权最小二乘求解：

\[
\min_c \|W(Ac-\tau_d)\|_2^2, \quad -1\le c_i\le 1
\]

由于该机器人没有侧向推进器，侧向 \(F_y\) 不作为主要控制自由度。

## 控制任务

1. **水下定深前进**：深度 PD + 速度 P + 航向 PD。
2. **转弯**：保持深度和前进速度，同时给定 90° 航向变化。
3. **矩形轨迹追踪**：使用 waypoint guidance，依次跟踪矩形四个边，并用航向控制器指向当前目标点。

该模型不是高精度 CFD，也没有真实推进器曲线；它是一个参数透明、可解释、可运行、适合课程演示和二次开发的动力学仿真基线。

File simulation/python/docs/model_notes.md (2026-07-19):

# 原始 `simulatedrobot.zip` 模型整理说明

## 原始包的用途

`simulatedrobot.zip` 是 SolidWorks URDF Exporter 导出的 ROS 描述包，包含：

- `urdf/simulatedrobot.urdf`：机器人 link/joint/inertial/mesh 描述；
- `meshes/*.STL`：主体与 5 个推进器几何；
- `launch/display.launch` 和 `launch/gazebo.launch`：RViz/Gazebo 加载入口。

它可以用于模型显示，但原始包不包含水动力、推进器推力模型、控制器或轨迹任务。

## 本工程对原模型的使用方式

本工程把 URDF 中的 5 个连续关节解释为 5 个推进器安装位：

| 推进器 | 原 joint | 本工程功能 |
|---|---|---|
| front_vertical | `frontwheeljoint` | 垂向推进器，用于深度、俯仰控制 |
| rear_right_vertical | `rbj` | 垂向推进器，用于深度、横滚/俯仰控制 |
| rear_left_vertical | `lbj` | 垂向推进器，用于深度、横滚/俯仰控制 |
| left_horizontal | `lfj` | 水平推进器，用于前进和偏航控制 |
| right_horizontal | `rfj` | 水平推进器，用于前进和偏航控制 |

仿真坐标系定义为：

- body X：前进方向；
- body Y：左侧方向；
- body Z：上方；
- world Z：上方；
- depth = `-world_z`。

原 CAD/URDF 的主体网格大致范围为：`x=[-0.187, 0.156]`, `y=[-1.556, -1.0]`, `z=[-0.081, 0.089]`。因此本工程使用 `[-0.015387, -1.2703, 0.0053548]` 作为仿真 body 原点。

## 对 URDF 的修正

`robot_description/simulatedrobot/urdf/simulatedrobot_fixed.urdf` 做了两个必要修正：

1. `rfw` 原始质量和惯量为 0，已改为与其它小推进器一致，避免物理仿真报错或发散。
2. `base_link` 原始惯性中心疑似 Y/Z 坐标互换，已把 `xyz="-0.015387 0.0053548 1.2703"` 修正为 `xyz="-0.015387 -1.2703 0.0053548"`。

这个 fixed URDF 主要用于 RViz/Gazebo 显示。真正完成定深、转弯和矩形轨迹任务的是 Python 动力学仿真器。

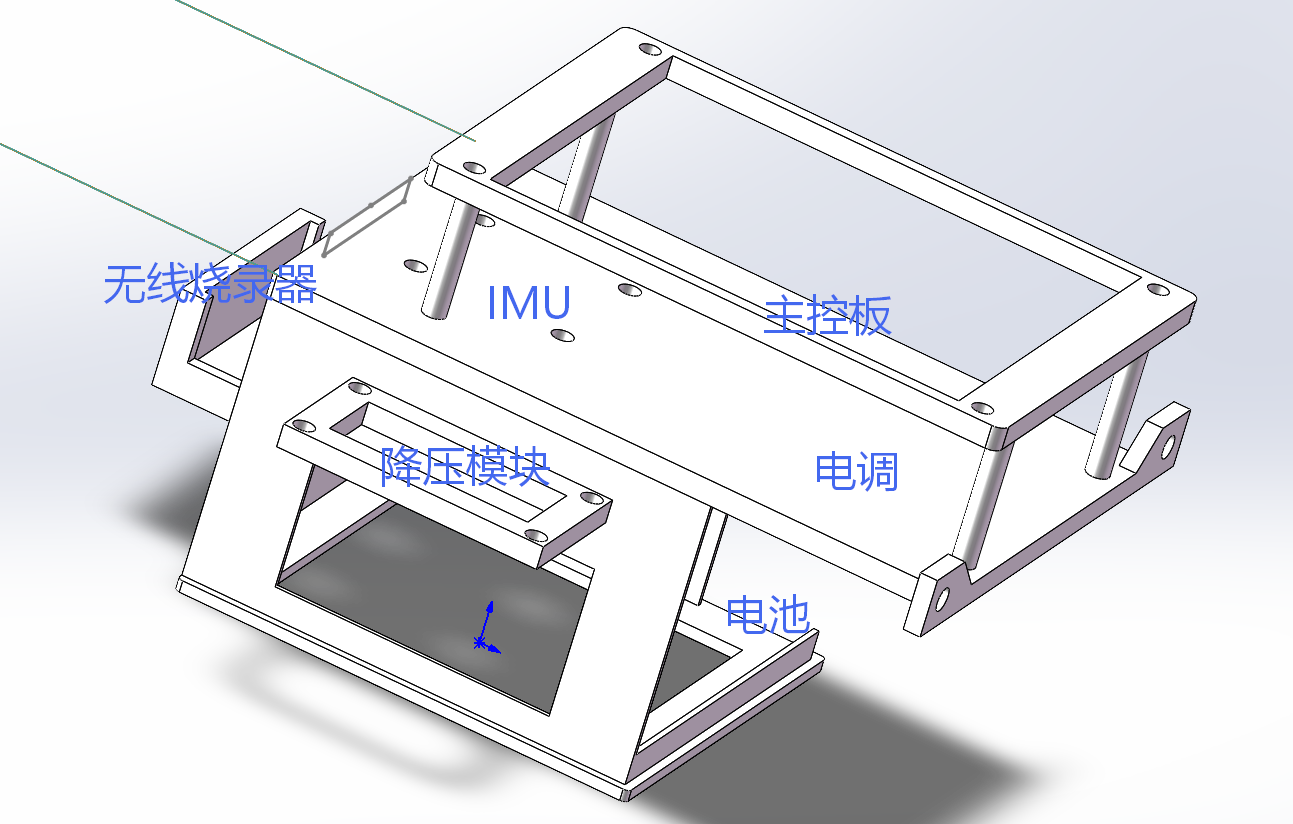
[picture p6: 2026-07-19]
docs/assets/electronics-layout.png

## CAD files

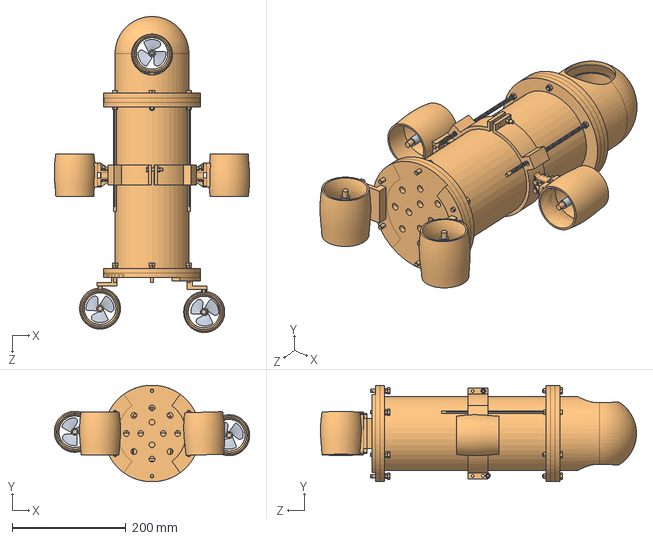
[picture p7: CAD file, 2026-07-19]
mechanical/solidworks/装配体（水平推进器简化）.SLDASM
343.8 x 169.7 x 556.1 mm
外径130x300密封舱总装整体无桨叶.STEP
垂推螺旋桨 x 5

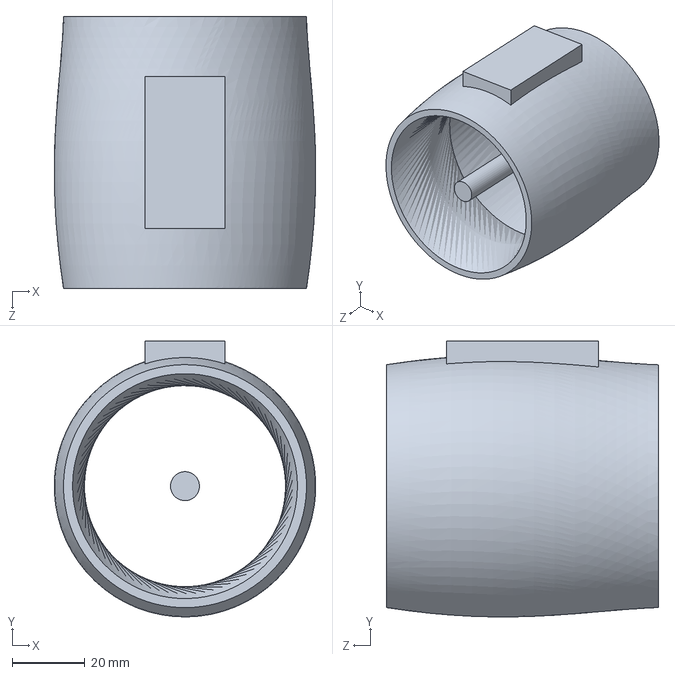
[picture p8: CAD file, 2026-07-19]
mechanical/solidworks/垂直推进器2.SLDPRT
72.1 x 76.1 x 75.0 mm

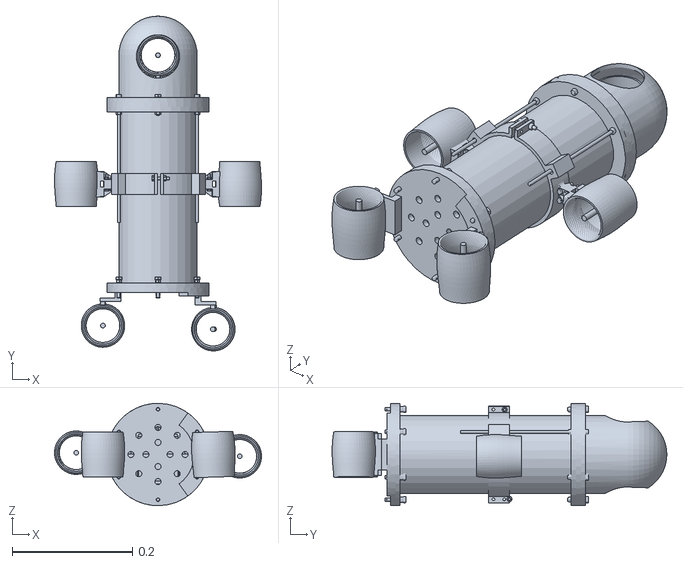
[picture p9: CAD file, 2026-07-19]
simulation/ros/simulatedrobot/meshes/base_link.STL
0.344 x 0.556 x 0.17

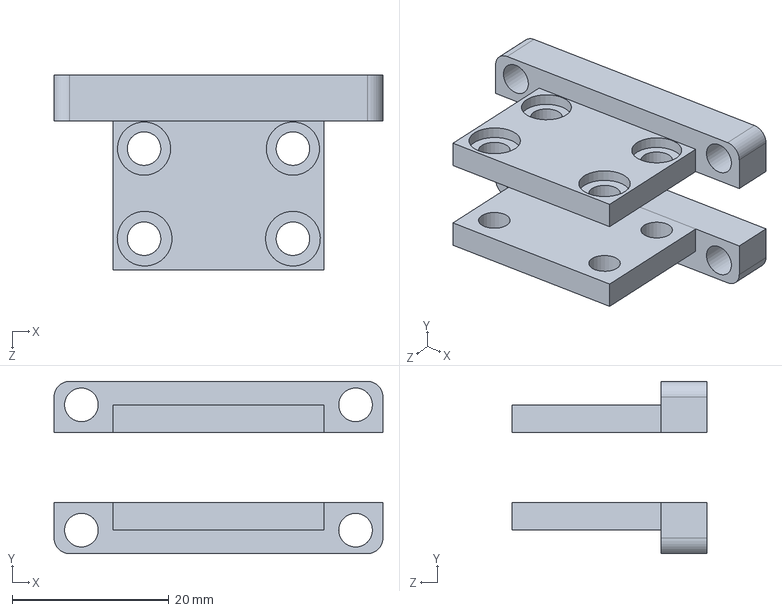
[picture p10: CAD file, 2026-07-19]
mechanical/solidworks/水平推进器连接件2_2.SLDPRT
42.0 x 22.0 x 24.9 mm

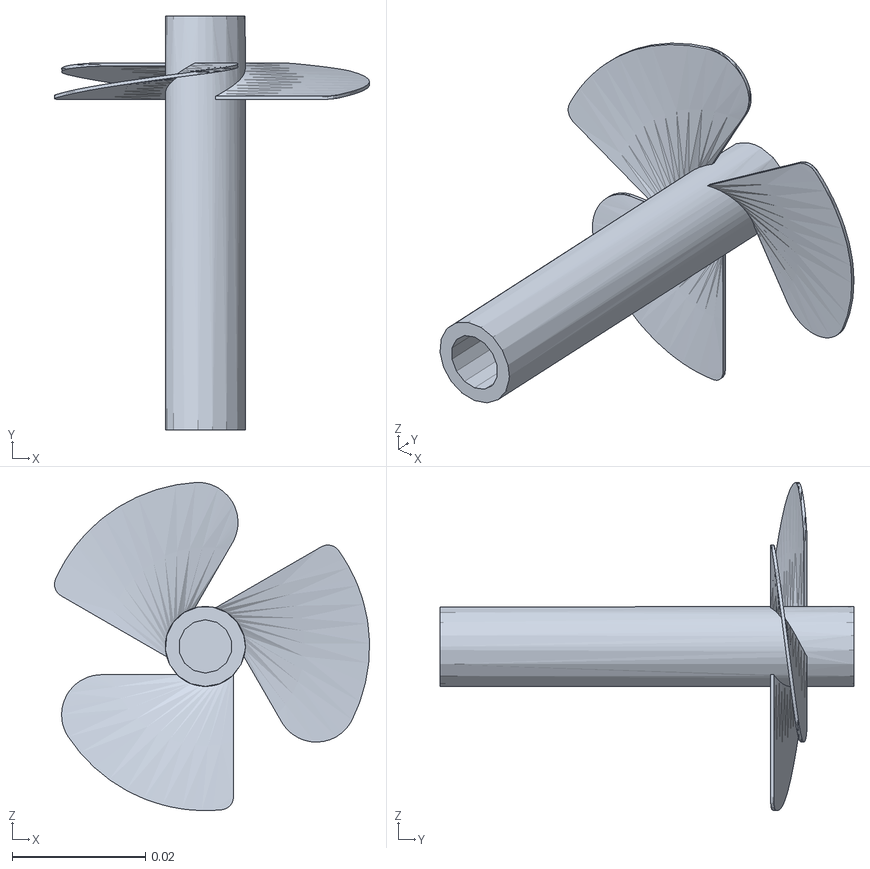
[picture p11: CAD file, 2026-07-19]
simulation/ros/simulatedrobot/meshes/lbw.STL
0.0472 x 0.062 x 0.0492

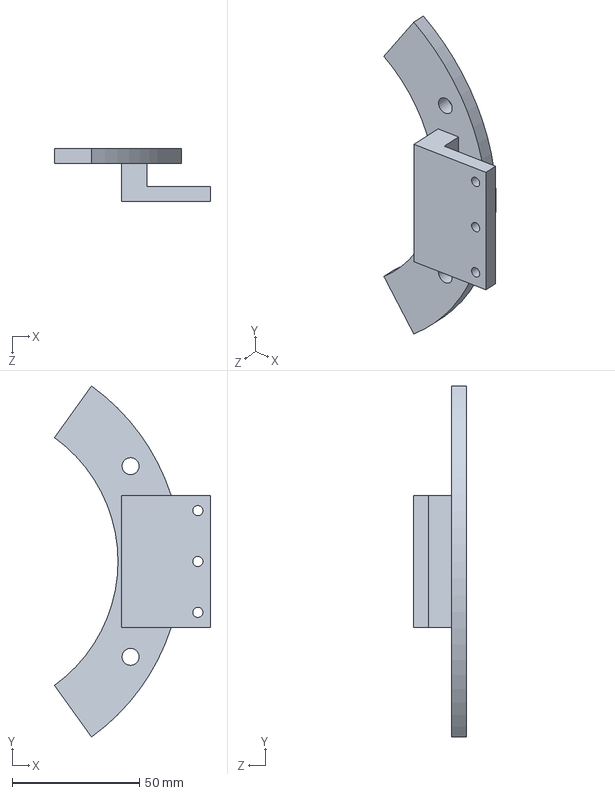
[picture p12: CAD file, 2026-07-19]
mechanical/solidworks/尾部垂推连接件2.SLDPRT
61.4 x 138.1 x 21.0 mm

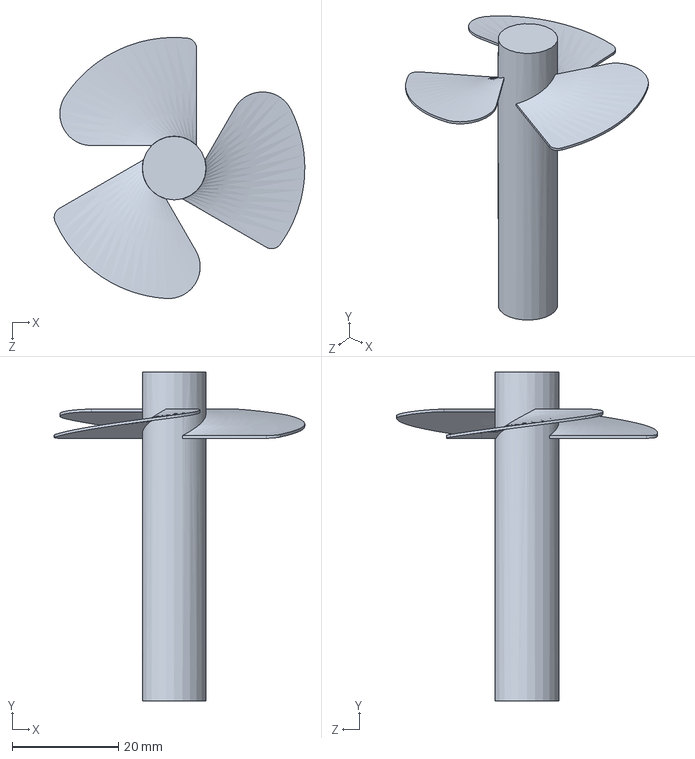
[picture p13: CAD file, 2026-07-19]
mechanical/solidworks/垂推螺旋桨.SLDPRT
47.2 x 62.0 x 49.2 mm

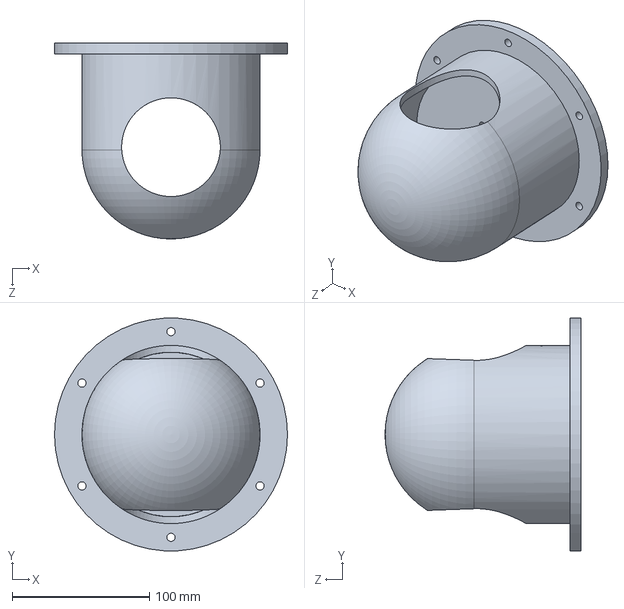
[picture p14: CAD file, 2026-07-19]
mechanical/solidworks/头部圆壳.SLDPRT
170.0 x 169.7 x 143.0 mm

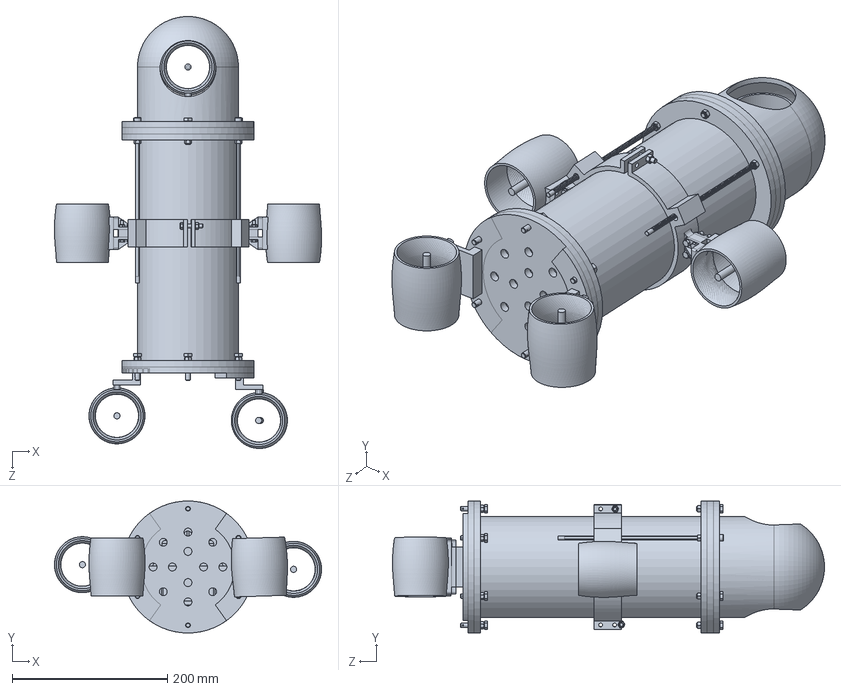
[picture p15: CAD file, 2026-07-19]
mechanical/solidworks/外径130x300密封舱总装整体无桨叶.STEP.SLDPRT
343.8 x 169.7 x 556.1 mm

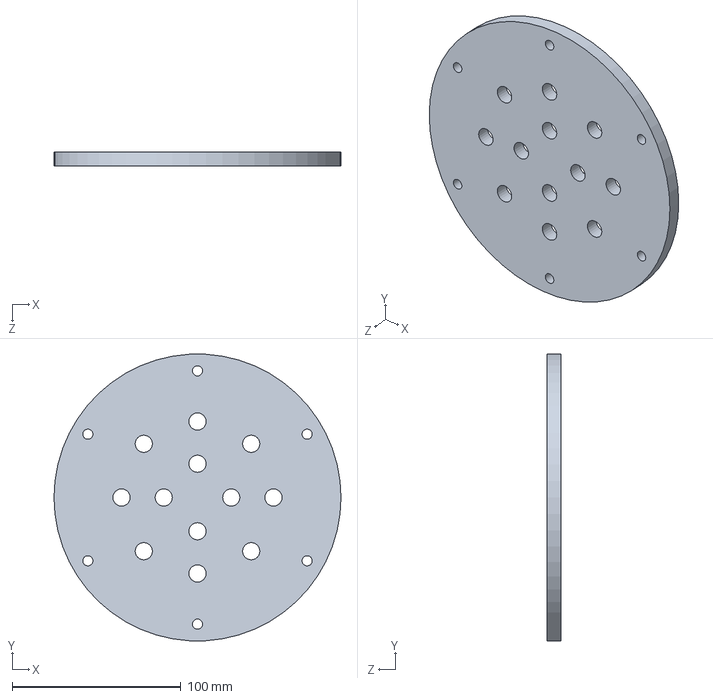
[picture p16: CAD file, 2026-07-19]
mechanical/solidworks/130盖子.SLDPRT
170.0 x 169.7 x 8.00 mm

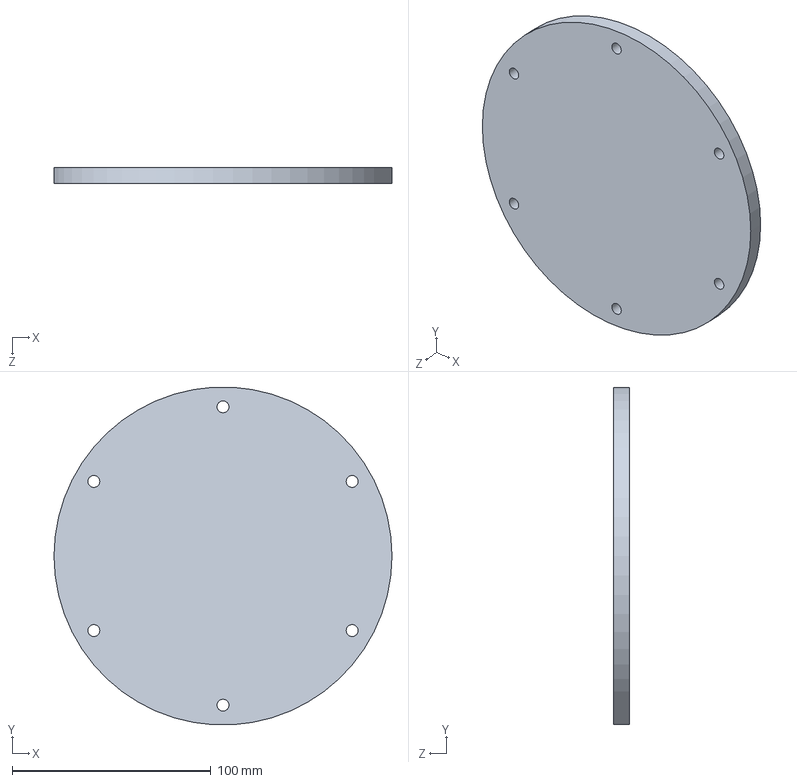
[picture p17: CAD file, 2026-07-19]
mechanical/solidworks/130盖子无孔2.SLDPRT
170.0 x 169.7 x 8.00 mm

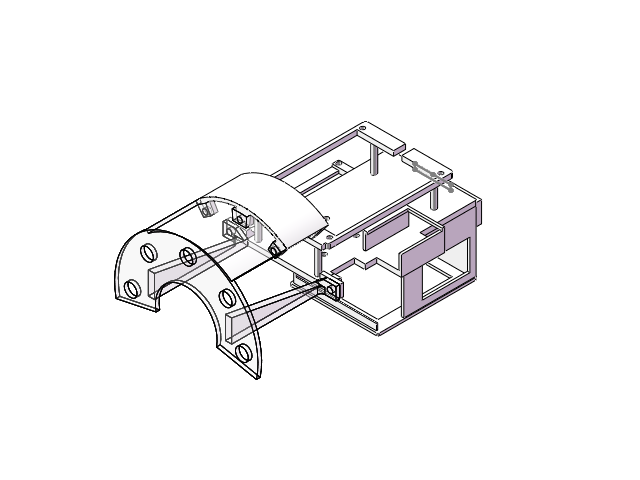
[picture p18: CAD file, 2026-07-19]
mechanical/solidworks/分隔板+连接件.SLDASM
分隔板固定件4.0(14mm)
超级无敌霹雳分隔板4.0

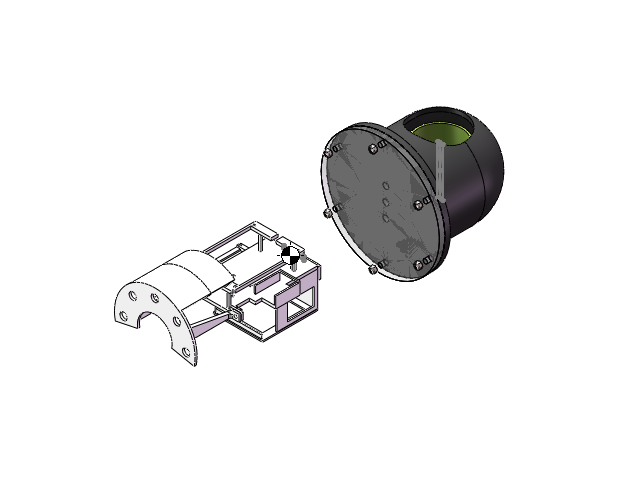
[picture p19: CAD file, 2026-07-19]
mechanical/solidworks/外径130x300密封舱总装2.SLDASM
hex nuts, style 1-grades ab gb x 6
130盖子无孔2
头部圆壳2
垂直推进器3
超级无敌霹雳分隔板4.0
分隔板固定件4.0(14mm)

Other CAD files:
simulation/ros/simulatedrobot/meshes/lfw.STL
simulation/ros/simulatedrobot/meshes/frontwheel.STL
simulation/ros/simulatedrobot/meshes/rbw.STL
mechanical/solidworks/垂直推进器3.SLDPRT
simulation/ros/simulatedrobot/meshes/rfw.STL
mechanical/solidworks/130半球罩.SLDPRT
mechanical/solidworks/130盖子2.SLDPRT
mechanical/solidworks/130盖子无孔.SLDPRT
mechanical/solidworks/5M螺栓.SLDPRT
mechanical/solidworks/VIOCEAN-T60（3kg推力）.step.SLDPRT
mechanical/solidworks/垂直推进器.SLDPRT
mechanical/solidworks/外径130x300密封舱2.SLDPRT
mechanical/solidworks/尾部垂推连接件1.SLDPRT
mechanical/solidworks/水平推进器连接件.SLDPRT

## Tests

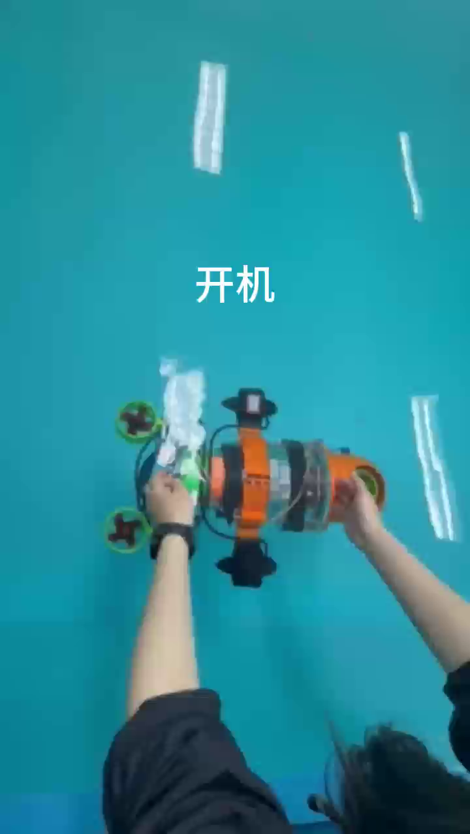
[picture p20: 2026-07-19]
docs/assets/pool-straight-turn-test.png

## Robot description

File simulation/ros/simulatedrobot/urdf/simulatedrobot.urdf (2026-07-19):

<?xml version="1.0" encoding="utf-8"?>
<!-- This URDF was automatically created by SolidWorks to URDF Exporter! Originally created by Stephen Brawner (brawner@gmail.com) 
     Commit Version: 1.6.0-4-g7f85cfe  Build Version: 1.6.7995.38578
     For more information, please see http://wiki.ros.org/sw_urdf_exporter -->
<robot name="simulatedrobot">
  <link name="base_link">
    <inertial>
      <origin xyz="-0.015387 0.0053548 1.2703" rpy="0 0 0" />
      <mass value="2.1846" />
      <inertia ixx="0.011681" ixy="-6.5459E-06" ixz="-4.3776E-06" iyy="0.011662" iyz="-3.337E-05" izz="0.0065666" />
    </inertial>
    <visual>
      <origin xyz="0 0 0" rpy="0 0 0" />
      <geometry>
        <mesh filename="package://simulatedrobot/meshes/base_link.STL" />
      </geometry>
      <material name="">
        <color rgba="1 1 1 1" />
      </material>
    </visual>
    <collision>
      <origin xyz="0 0 0" rpy="0 0 0" />
      <geometry>
        <mesh filename="package://simulatedrobot/meshes/base_link.STL" />
      </geometry>
    </collision>
  </link>
  <link name="frontwheel">
    <inertial>
      <origin xyz="-1.0713E-08 0.0053748 -3.0224E-08" rpy="0 0 0" />
      <mass value="0.0046375" />
      <inertia ixx="1.7181E-06" ixy="4.5058E-13" ixz="-7.8408E-14" iyy="3.0171E-07" iyz="1.9638E-12" izz="1.7181E-06" />
    </inertial>
    <visual>
      <origin xyz="0 0 0" rpy="0 0 0" />
      <geometry>
        <mesh filename="package://simulatedrobot/meshes/frontwheel.STL" />
      </geometry>
      <material name="">
        <color rgba="1 1 1 1" />
      </material>
    </visual>
    <collision>
      <origin xyz="0 0 0" rpy="0 0 0" />
      <geometry>
        <mesh filename="package://simulatedrobot/meshes/frontwheel.STL" />
      </geometry>
    </collision>
  </link>
  <joint name="frontwheeljoint" type="continuous">
    <origin xyz="-0.015431 -1.065 0" rpy="-1.5708 0 -0.57871" />
    <parent link="base_link" />
    <child link="frontwheel" />
    <axis xyz="0 1 0" />
  </joint>
  <link name="rbw">
    <inertial>
      <origin xyz="-1.0713E-08 0.0051351 -3.0224E-08" rpy="0 0 0" />
      <mass value="0.0046375" />
      <inertia ixx="1.7181E-06" ixy="4.5058E-13" ixz="-7.8408E-14" iyy="3.0171E-07" iyz="1.9638E-12" izz="1.7181E-06" />
    </inertial>
    <visual>
      <origin xyz="0 0 0" rpy="0 0 0" />
      <geometry>
        <mesh filename="package://simulatedrobot/meshes/rbw.STL" />
      </geometry>
      <material name="">
        <color rgba="1 1 1 1" />
      </material>
    </visual>
    <collision>
      <origin xyz="0 0 0" rpy="0 0 0" />
      <geometry>
        <mesh filename="package://simulatedrobot/meshes/rbw.STL" />
      </geometry>
    </collision>
  </link>
  <joint name="rbj" type="continuous">
    <origin xyz="-0.10685 -1.514 0" rpy="-1.5708 0 2.5629" />
    <parent link="base_link" />
    <child link="rbw" />
    <axis xyz="0 1 0" />
  </joint>
  <link name="lbw">
    <inertial>
      <origin xyz="7.7736E-08 0.0074848 -1.5396E-07" rpy="0 0 0" />
      <mass value="0.0046375" />
      <inertia ixx="1.7181E-06" ixy="-5.9633E-12" ixz="-1.63E-12" iyy="3.0171E-07" iyz="9.0528E-12" izz="1.7181E-06" />
    </inertial>
    <visual>
      <origin xyz="0 0 0" rpy="0 0 0" />
      <geometry>
        <mesh filename="package://simulatedrobot/meshes/lbw.STL" />
      </geometry>
      <material name="">
        <color rgba="1 1 1 1" />
      </material>
    </visual>
    <collision>
      <origin xyz="0 0 0" rpy="0 0 0" />
      <geometry>
        <mesh filename="package://simulatedrobot/meshes/lbw.STL" />
      </geometry>
    </collision>
  </link>
  <joint name="lbj" type="continuous">
    <origin xyz="0.076668 -1.52 0.0023601" rpy="-1.5876 0.025813 2.5657" />
    <parent link="base_link" />
    <child link="lbw" />
    <axis xyz="0 1 0" />
  </joint>
  <link name="lfw">
    <inertial>
      <origin xyz="3.366E-08 -0.027425 1.7595E-08" rpy="0 0 0" />
      <mass value="0.0046375" />
      <inertia ixx="1.7181E-06" ixy="-1.974E-12" ixz="-1.955E-13" iyy="3.0171E-07" iyz="-1.3411E-12" izz="1.7181E-06" />
    </inertial>
    <visual>
      <origin xyz="0 0 0" rpy="0 0 0" />
      <geometry>
        <mesh filename="package://simulatedrobot/meshes/lfw.STL" />
      </geometry>
      <material name="">
        <color rgba="1 1 1 1" />
      </material>
    </visual>
    <collision>
      <origin xyz="0 0 0" rpy="0 0 0" />
      <geometry>
        <mesh filename="package://simulatedrobot/meshes/lfw.STL" />
      </geometry>
    </collision>
  </link>
  <joint name="lfj" type="continuous">
    <origin xyz="0.12044 -1.2421 0.0014413" rpy="0 -0.39309 0" />
    <parent link="base_link" />
    <child link="lfw" />
    <axis xyz="0 1 0" />
  </joint>
  <link name="rfw">
    <inertial>
      <origin xyz="0 0 0" rpy="0 0 0" />
      <mass value="0" />
      <inertia ixx="0" ixy="0" ixz="0" iyy="0" iyz="0" izz="0" />
    </inertial>
    <visual>
      <origin xyz="0 0 0" rpy="0 0 0" />
      <geometry>
        <mesh filename="package://simulatedrobot/meshes/rfw.STL" />
      </geometry>
      <material name="">
        <color rgba="1 1 1 1" />
      </material>
    </visual>
    <collision>
      <origin xyz="0 0 0" rpy="0 0 0" />
      <geometry>
        <mesh filename="package://simulatedrobot/meshes/rfw.STL" />
      </geometry>
    </collision>
  </link>
  <joint name="rfj" type="continuous">
    <origin xyz="-0.1513 -1.2421 0.0074378" rpy="0 0 0" />
    <parent link="base_link" />
    <child link="rfw" />
    <axis xyz="0 1 0" />
  </joint>
</robot>

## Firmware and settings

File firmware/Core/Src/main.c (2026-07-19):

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
/* Includes ------------------------------------------------------------------*/
#include "main.h"
#include "cmsis_os.h"
#include "dma.h"
#include "i2c.h"
#include "tim.h"
#include "usart.h"
#include "gpio.h"

/* USER CODE BEGIN Includes */
#include "MS5837.h"
/* USER CODE END Includes */


/* USER CODE BEGIN PV */
#include "robot_def.h"

RobotState_t g_robotState = {0}; // 初始化
/* USER CODE END PV */

void SystemClock_Config(void);
void MX_FREERTOS_Init(void);
/**
  * @brief  The application entry point.
  * @retval int
  */
int main(void)
{

  /* MCU Configuration--------------------------------------------------------*/

  /* Reset of all peripherals, Initializes the Flash interface and the Systick. */
  HAL_Init();

  /* Configure the system clock */
  SystemClock_Config();

  /* Initialize all configured peripherals */
  MX_GPIO_Init();
  MX_DMA_Init();
  MX_I2C1_Init();
  MX_USART6_UART_Init();
  MX_TIM2_Init();
  MX_TIM3_Init();
  MX_USART3_UART_Init();
  /* USER CODE BEGIN 2 */
  // ====== 上电自检: 红+绿同时亮 1 秒 ======
  // 看到这个 = 新固件已成功烧录
  HAL_GPIO_WritePin(LED0_RED_GPIO_Port,   LED0_RED_Pin,   GPIO_PIN_RESET);
  HAL_GPIO_WritePin(LED1_GREEN_GPIO_Port, LED1_GREEN_Pin, GPIO_PIN_RESET);
  HAL_Delay(1000);
  HAL_GPIO_WritePin(LED0_RED_GPIO_Port,   LED0_RED_Pin,   GPIO_PIN_SET);
  HAL_GPIO_WritePin(LED1_GREEN_GPIO_Port, LED1_GREEN_Pin, GPIO_PIN_SET);
  HAL_Delay(200);
  /* USER CODE END 2 */

  /* Init scheduler */
  osKernelInitialize();  /* Call init function for freertos objects (in cmsis_os2.c) */
  MX_FREERTOS_Init();

  /* Start scheduler */
  osKernelStart();

  /* We should never get here as control is now taken by the scheduler */

  /* Infinite loop */
  /* USER CODE BEGIN WHILE */
  while (1)
  {
    HAL_Delay(10000);
    /* USER CODE END WHILE */

    /* USER CODE BEGIN 3 */
  }
  /* USER CODE END 3 */
}

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
/**
  * @brief  Period elapsed callback in non blocking mode
  * @note   This function is called  when TIM7 interrupt took place, inside
  * HAL_TIM_IRQHandler(). It makes a direct call to HAL_IncTick() to increment
  * a global variable "uwTick" used as application time base.
  * @param  htim : TIM handle
  * @retval None
  */
void HAL_TIM_PeriodElapsedCallback(TIM_HandleTypeDef *htim)
{
  if (htim->Instance == TIM7)
  {
    HAL_IncTick();
  }
}

/**
  * @brief  This function is executed in case of error occurrence.
  * @retval None
  */
void Error_Handler(void)
{
  /* USER CODE BEGIN Error_Handler_Debug */
  /* User can add his own implementation to report the HAL error return state */
  __disable_irq();
  // Error 指示: 红灯常亮 (低电平点亮, 共阳极接法)
  HAL_GPIO_WritePin(LED0_RED_GPIO_Port, LED0_RED_Pin, GPIO_PIN_RESET);
  HAL_GPIO_WritePin(LED1_GREEN_GPIO_Port, LED1_GREEN_Pin, GPIO_PIN_SET); // 绿灯灭
  while (1)
  {
  }
  /* USER CODE END Error_Handler_Debug */
}
#ifdef USE_FULL_ASSERT
/**
  * @brief  Reports the name of the source file and the source line number
  *         where the assert_param error has occurred.
  * @param  file: pointer to the source file name
  * @param  line: assert_param error line source number
  * @retval None
  */
void assert_failed(uint8_t *file, uint32_t line)
{
  /* USER CODE BEGIN 6 */
  /* User can add his own implementation to report the file name and line number,
     ex: printf("Wrong parameters value: file %s on line %d\r\n", file, line) */
  /* USER CODE END 6 */
}
#endif /* USE_FULL_ASSERT */

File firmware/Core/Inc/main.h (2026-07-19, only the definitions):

#define LED0_RED_Pin GPIO_PIN_9
#define LED0_RED_GPIO_Port GPIOF
#define LED1_GREEN_Pin GPIO_PIN_10
#define LED1_GREEN_GPIO_Port GPIOF
#define VF_Pin GPIO_PIN_1
#define VF_GPIO_Port GPIOA
#define VRL_Pin GPIO_PIN_2
#define VRL_GPIO_Port GPIOA
#define VRR_Pin GPIO_PIN_3
#define VRR_GPIO_Port GPIOA
#define HL_Pin GPIO_PIN_0
#define HL_GPIO_Port GPIOB
#define HR_Pin GPIO_PIN_1
#define HR_GPIO_Port GPIOB
#define LoRa_TX_Pin GPIO_PIN_8
#define LoRa_TX_GPIO_Port GPIOD
#define LoRa_RX_Pin GPIO_PIN_9
#define LoRa_RX_GPIO_Port GPIOD
#define IMU_TX_Pin GPIO_PIN_6
#define IMU_TX_GPIO_Port GPIOC
#define IMU_RX_Pin GPIO_PIN_7
#define IMU_RX_GPIO_Port GPIOC
#define PDS_SCL_Pin GPIO_PIN_6
#define PDS_SCL_GPIO_Port GPIOB
#define PDS_SDA_Pin GPIO_PIN_7
#define PDS_SDA_GPIO_Port GPIOB

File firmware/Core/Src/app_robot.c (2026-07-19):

#include "app_robot.h"
#include "cmsis_os.h"
#include "robot_def.h"
#include "usart.h"
#include "string.h"
#include "analysis_data.h"
#include "MS5837.h"
#include "pid.h"
#include "mixer.h"
#include "motor_pwm.h"
#include <math.h>

// ================= LED 指示灯宏 =================
// 共阳极接法: RESET=亮, SET=灭
#define LED_RED_ON()      HAL_GPIO_WritePin(LED0_RED_GPIO_Port,  LED0_RED_Pin,  GPIO_PIN_RESET)
#define LED_RED_OFF()     HAL_GPIO_WritePin(LED0_RED_GPIO_Port,  LED0_RED_Pin,  GPIO_PIN_SET)
#define LED_RED_TOGGLE()  HAL_GPIO_TogglePin(LED0_RED_GPIO_Port, LED0_RED_Pin)

// ================= LORA 变量 =================
#define LORA_RX_BUF_SIZE 64
uint8_t lora_rx_buf[LORA_RX_BUF_SIZE];
volatile uint8_t lora_data_len = 0;    // ISR 写, Task 读, 必须 volatile

// --- LoRa TX ---
#define LORA_TX_BUF_SIZE 64
static uint8_t lora_tx_buf[LORA_TX_BUF_SIZE];

// LoRa 定点传输头: 目标地址(0x00 0x00) + 信道(0x17)
#define LORA_PC_ADDR_H  0x00
#define LORA_PC_ADDR_L  0x00
#define LORA_CHANNEL    0x17
#define TELEM_FUNC_ID   0x80
#define TELEM_INTERVAL_MS  500   // 回传间隔 500ms (2Hz)

// 回传 Payload
#pragma pack(push, 1)
typedef struct {
    uint8_t  mode;
    float    depth;
    float    yaw;
    float    pitch;
    float    roll;
    float    target_depth;
    float    target_yaw;
    float    speed;          // 估算前进速度 (m/s)
    float    surge;          // 当前前进推力
} TelemetryPayload_t;   // 33 字节
#pragma pack(pop)

// ================= IMU 变量 =================
#define IMU_RX_BUF_SIZE 256
uint8_t imu_rx_buf[IMU_RX_BUF_SIZE];
volatile uint8_t imu_data_len = 0;

// ================= PID 实例 =================
static PID_Controller_t pid_depth;
static PID_Controller_t pid_pitch;
static PID_Controller_t pid_roll;
static PID_Controller_t pid_yaw;

// ================= 混控实例 =================
static MixerCoeff_t mixer_coeff;
static MotorOutput_t motor_output;

// ============================================================
//  StartControlTask - 核心闭环控制 (Realtime 优先级)
// ============================================================
void StartControlTask(void *argument)
{
    Command_t recv_cmd;

    PID_Init(&pid_depth, 2.0f, 0.3f, 0.5f,  1.0f,  -1.0f,   0.5f,   0.01f);
    PID_Init(&pid_pitch, 1.5f, 0.1f, 0.3f,  0.5f,  -0.5f,   0.3f,   0.5f);
    PID_Init(&pid_roll,  1.5f, 0.1f, 0.3f,  0.5f,  -0.5f,   0.3f,   0.5f);
    PID_Init(&pid_yaw,   1.0f, 0.05f,0.2f,  0.8f,  -0.8f,   0.3f,   1.0f);

    Mixer_Init(&mixer_coeff, 0.5f, 0.5f, 0.5f, 0.5f);
    Motor_PWM_Init();

    // ESC arming: 中位 3 秒
    osDelay(3000);

    // IMU: 开启 IDLE 中断 + DMA
    __HAL_UART_CLEAR_IDLEFLAG(&huart6);
    __HAL_UART_ENABLE_IT(&huart6, UART_IT_IDLE);
    HAL_UART_Receive_DMA(&huart6, imu_rx_buf, IMU_RX_BUF_SIZE);

    uint32_t last_tick = osKernelGetTickCount();

    for(;;)
    {
        // 0. 计算 dt (必须在 IMU 速度估算之前)
        uint32_t now_tick = osKernelGetTickCount();
        float dt = (float)(now_tick - last_tick) / 1000.0f;
        last_tick = now_tick;
        if (dt <= 0.0f || dt > 0.5f) dt = 0.01f;

        // 1. 非阻塞检查指令队列
        if (osMessageQueueGet(Queues_CmdHandle, &recv_cmd, NULL, 0) == osOK)
        {
            osMutexAcquire(Mutex_StateHandle, osWaitForever);
            if (recv_cmd.cmd_type == 1) {
                // HOVER: 定深悬停
                g_robotState.current_mode = MODE_HOVER;
                g_robotState.target_depth = recv_cmd.param1;
                g_robotState.target_pitch = 0.0f;
                g_robotState.target_roll  = 0.0f;
                g_robotState.target_surge = 0.0f;
            } else if (recv_cmd.cmd_type == 2) {
                // AUTO: 直航 (锁定当前航向)
                g_robotState.current_mode = MODE_AUTO;
                g_robotState.target_surge = recv_cmd.param1;
                g_robotState.target_yaw   = g_robotState.current_yaw;
                g_robotState.target_pitch = 0.0f;
                g_robotState.target_roll  = 0.0f;
            } else if (recv_cmd.cmd_type == 4) {
                // TURN: 转向到指定航向
                g_robotState.current_mode = MODE_TURN;
                g_robotState.target_yaw   = recv_cmd.param1;
                g_robotState.target_surge = 0.0f;
                g_robotState.target_pitch = 0.0f;
                g_robotState.target_roll  = 0.0f;
            } else if (recv_cmd.cmd_type == 5) {
                // SQUARE: 方形轨迹自动导航
                g_robotState.current_mode       = MODE_SQUARE;
                g_robotState.sq_leg             = 0;
                g_robotState.sq_phase           = 0;  // 从直行开始
                g_robotState.sq_surge           = recv_cmd.param2;  // 推力
                g_robotState.sq_leg_duration_ms = (uint32_t)(recv_cmd.param1 * 1000.0f); // 边时长
                g_robotState.sq_start_yaw       = g_robotState.current_yaw;
                g_robotState.target_yaw         = g_robotState.current_yaw;
                g_robotState.target_surge       = recv_cmd.param2;
                g_robotState.target_pitch       = 0.0f;
                g_robotState.target_roll        = 0.0f;
                g_robotState.sq_phase_start_tick = osKernelGetTickCount();
            } else {
                // STOP / IDLE
                g_robotState.current_mode = MODE_IDLE;
                g_robotState.target_surge = 0.0f;
                g_robotState.estimated_speed = 0.0f;
            }
            osMutexRelease(Mutex_StateHandle);
        }

        // 2. 等待 IMU 信号量
        if (osSemaphoreAcquire(Sem_IMU_ReadyHandle, 200) == osOK)
        {
            int ret = analysis_data(imu_rx_buf, imu_data_len);
            if (ret == analysis_ok)
            {
                osMutexAcquire(Mutex_StateHandle, osWaitForever);
                g_robotState.current_yaw   = g_output_info.yaw;
                g_robotState.current_pitch = g_output_info.pitch;
                g_robotState.current_roll  = g_output_info.roll;
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

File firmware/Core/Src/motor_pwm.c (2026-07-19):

//
// Created by DS on 2026/3/9.
// 电机 PWM 输出驱动实现

#include "motor_pwm.h"
#include "stm32f4xx_hal.h"

extern TIM_HandleTypeDef htim2;
extern TIM_HandleTypeDef htim3;

typedef struct {
    TIM_HandleTypeDef *htim;
    uint32_t channel;
} MotorPWMMap_t;

static const MotorPWMMap_t motor_map[MOT_COUNT] = {
    [MOT_VF]  = { &htim2, TIM_CHANNEL_2 },  // PA1 - 垂直前方
    [MOT_VRL] = { &htim2, TIM_CHANNEL_3 },  // PA2 - 垂直尾左
    [MOT_VRR] = { &htim2, TIM_CHANNEL_4 },  // PA3 - 垂直尾右
    [MOT_HL]  = { &htim3, TIM_CHANNEL_3 },  // PB0 - 水平左
    [MOT_HR]  = { &htim3, TIM_CHANNEL_4 },  // PB1 - 水平右
};

// === 辅助: 推力归一化值转 PWM CCR ===
static uint16_t Thrust_To_CCR(float thrust)
{
    // 限幅
    if (thrust >  1.0f) thrust =  1.0f;
    if (thrust < -1.0f) thrust = -1.0f;

    // [-1.0, +1.0] → [1000, 2000]
    return (uint16_t)(PWM_NEUTRAL + thrust * (PWM_MAX - PWM_NEUTRAL));
}

// -------------------------------------------------------
void Motor_PWM_Init(void)
{

    // 启动所有 PWM 通道, 初始输出中位
    for (int i = 0; i < MOT_COUNT; i++)
    {
        __HAL_TIM_SET_COMPARE(motor_map[i].htim, motor_map[i].channel, PWM_NEUTRAL);
        HAL_TIM_PWM_Start(motor_map[i].htim, motor_map[i].channel);
    }
}

// -------------------------------------------------------
void Motor_PWM_Set(MotorIndex_e index, float thrust)
{
    if (index >= MOT_COUNT) return;

    uint16_t ccr = Thrust_To_CCR(thrust);
    __HAL_TIM_SET_COMPARE(motor_map[index].htim, motor_map[index].channel, ccr);
}

// -------------------------------------------------------
void Motor_PWM_SetAll(const MotorOutput_t *out)
{
    for (int i = 0; i < MOT_COUNT; i++)
    {
        uint16_t ccr = Thrust_To_CCR(out->thrust[i]);
        __HAL_TIM_SET_COMPARE(motor_map[i].htim, motor_map[i].channel, ccr);
    }
}

// -------------------------------------------------------
void Motor_PWM_AllStop(void)
{
    for (int i = 0; i < MOT_COUNT; i++)
    {
        __HAL_TIM_SET_COMPARE(motor_map[i].htim, motor_map[i].channel, PWM_NEUTRAL);
    }
}

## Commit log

2026-07-06 Algorithm
    控制算法部分
2026-07-19 Reorganize repository and publish project source
    Replace opaque archives with browsable source, bilingual documentation, report-derived project images and hardware information, validated Python simulation, and recorded safety/code-review findings.
    [130半球罩.SLDPRT, 130盖子.SLDPRT, 130盖子2.SLDPRT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]

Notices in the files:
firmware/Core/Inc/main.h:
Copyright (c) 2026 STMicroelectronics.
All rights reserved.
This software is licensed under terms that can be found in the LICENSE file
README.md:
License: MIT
